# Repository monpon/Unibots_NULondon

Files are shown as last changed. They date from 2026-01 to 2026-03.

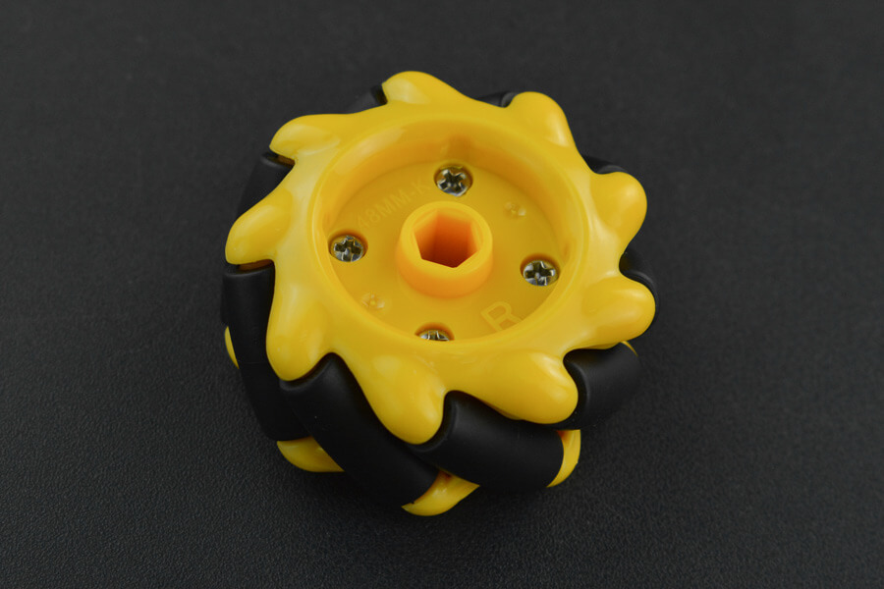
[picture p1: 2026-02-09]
hardware/chassis/FIT0662.jpg

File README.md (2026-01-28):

# Unibots UK Competition Robot

An autonomous robot system designed for the Unibots UK competition, featuring mecanum drive omnidirectional movement, AprilTag-based localization, and autonomous ball collection and launching capabilities.

## Competition Overview

The robot competes in a timed arena-based challenge to:
- Collect magnetic steel ball bearings
- Launch ping-pong balls into scoring nets
- Navigate autonomously with collision avoidance
- Operate within strict size constraints

## System Architecture

### Hardware Components

**Main Controller**
- Raspberry Pi 3 - Primary processing unit

**Motor Control**
- Arduino Uno - Motor control interface with FPID control loops
- 4x Motor encoders - Precise speed feedback for mecanum drive
- ESC units - Electronic speed controllers
- Mecanum wheel drive system - Omnidirectional movement

**Vision System**
- 2x USB webcams:
  - Camera 1: AprilTag localization
  - Camera 2: Ball/gamepiece detection
- AprilTag markers - Localization reference points

**Actuators**
- Ball collection mechanism
- Ping-pong ball launcher

### Software Stack

**Control Architecture**
```
Raspberry Pi 3 (Python)
    ↓ Position Targets via Serial
Arduino Uno (C++)
    ├─ FPID Control Loops (4 motors)
    ├─ Encoder Feedback
    ↓ PWM Signals
ESC Controllers
    ↓ Power
Brushless/DC Motors with Encoders
```

**Key Features**
- Dual camera system: AprilTag localization and object detection
- Encoder-based FPID control for precise mecanum drive
- Distributed control: Pi handles navigation, Arduino handles drive control
- Real-time position targeting with continuous updates
- Autonomous path planning and obstacle avoidance

## Getting Started

### Prerequisites

```bash
# Raspberry Pi dependencies
sudo apt-get update
sudo apt-get install python3-opencv python3-numpy
pip3 install apriltag pyserial

# Arduino IDE for motor control firmware
```

### Installation

```bash
# Clone the repository
git clone <repository-url>
cd unibots-robot/software

# Install Python dependencies
pip3 install -r requirements.txt

# Upload Arduino firmware
# Open arduino/motor_control/motor_control.ino in Arduino IDE
# Select Arduino Uno and upload
```

### Configuration

1. **Camera Calibration**: Calibrate each camera for lens distortion
2. **AprilTag Mapping**: Record arena AprilTag positions
3. **Encoder Calibration**: Calibrate encoder counts per revolution
4. **FPID Tuning**: Tune FPID parameters for each motor
5. **Serial Protocol**: Configure position target communication format

## Project Structure

```
unibots-robot/
├── README.md
├── software/
│   ├── requirements.txt
│   ├── config/
│   │   ├── camera_params.yaml
│   │   ├── apriltag_positions.yaml
│   │   ├── motor_calibration.yaml
│   │   └── fpid_params.yaml
│   ├── src/
│   │   ├── main.py
│   │   ├── vision/
│   │   │   ├── apriltag_detector.py
│   │   │   ├── camera_manager.py
│   │   │   └── localization.py
│   │   ├── navigation/
│   │   │   ├── path_planner.py
│   │   │   ├── obstacle_avoidance.py
│   │   │   └── position_targeting.py
│   │   ├── control/
│   │   │   └── arduino_interface.py
│   │   └── utils/
│   │       └── geometry.py
│   ├── arduino/
│   │   └── motor_control/
│   │       ├── motor_control.ino
│   │       ├── fpid.h
│   │       └── encoder.h
│   ├── tests/
│   │   └── test_localization.py
│   ├── tools/
│   │   ├── calibrate_cameras.py
│   │   ├── calibrate_motors.py
│   │   └── tune_fpid.py
│   └── docs/
│       ├── architecture.md
│       ├── serial_protocol.md
│       ├── calibration_guide.md
│       ├── fpid_tuning.md
│       └── competition_rules.md
└── hardware/
    ├── chassis/
    ├── motor_mounts/
    ├── camera_mounts/
    ├── ball_collector/
    ├── lifter/
    └── assembly/
```

## Usage

### Running the Robot

```bash
# Navigate to software directory
cd software

# Start the main control system
python3 src/main.py

# Run with debug visualization
python3 src/main.py --debug

# Test individual components
python3 tests/test_localization.py
```

### Calibration

```bash
# Camera calibration
python3 tools/calibrate_cameras.py

# Motor calibration
python3 tools/calibrate_motors.py

# FPID tuning
python3 tools/tune_fpid.py
```

## Development

### Key Design Decisions

- **Mecanum Drive**: Chosen for omnidirectional movement and precise positioning
- **Encoder-Based Control**: Four motor encoders provide precise speed feedback for synchronized mecanum drive
- **FPID Control**: Arduino handles real-time FPID loops for each motor, ensuring accurate speed matching
- **Distributed Architecture**: Raspberry Pi 3 handles high-level navigation and sends position targets; Arduino Uno executes low-level drive control
- **Camera-Based Odometry**: AprilTag localization with dedicated camera for position tracking

### Known Issues

- Motor selection: Need motors with integrated or attachable encoders
- Arduino Uno memory constraints with FPID for 4 motors + encoder processing
- Serial communication latency for position target updates
- Camera processing optimization needed for real-time performance with dual cameras

## Competition Constraints

- Initial size limitations must be met
- Full autonomy required (no remote control)
- Collision avoidance mandatory
- AprilTags positioned around arena walls for localization

## Contributing

1. Fork the repository
2. Create a feature branch (`git checkout -b feature/improvement`)
3. Commit changes (`git commit -am 'Add new feature'`)
4. Push to branch (`git push origin feature/improvement`)
5. Open a Pull Request

## Contact

Monesh - moneshpon@gmail.com

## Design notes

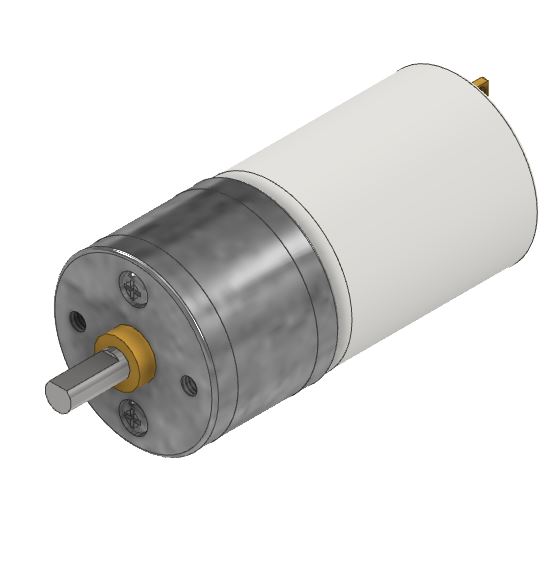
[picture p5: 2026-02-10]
hardware/motor_mounts/25ga-370-280-rpm-dc-motor-1.snapshot.1/25ga-370-280-rpm-dc Motor.JPG

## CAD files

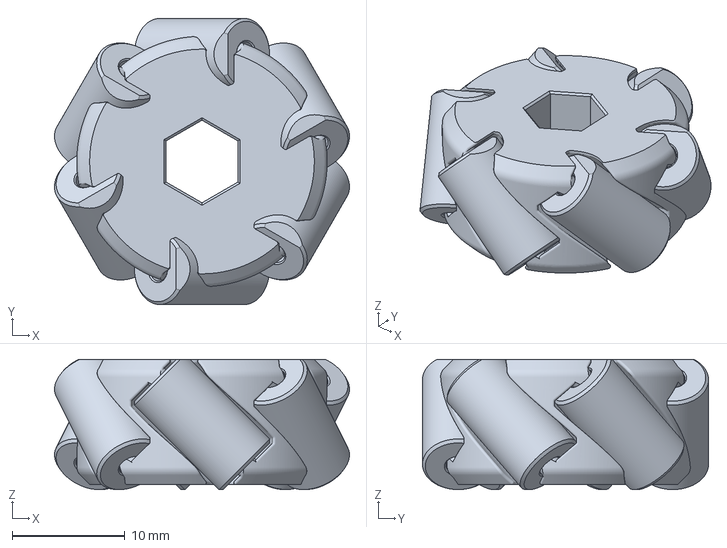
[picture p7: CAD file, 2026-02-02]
hardware/chassis/2910, 2in, Preassembled, 3DP, Mechanum Wheel, Left.3mf
26.2 x 25.4 x 11.6 mm

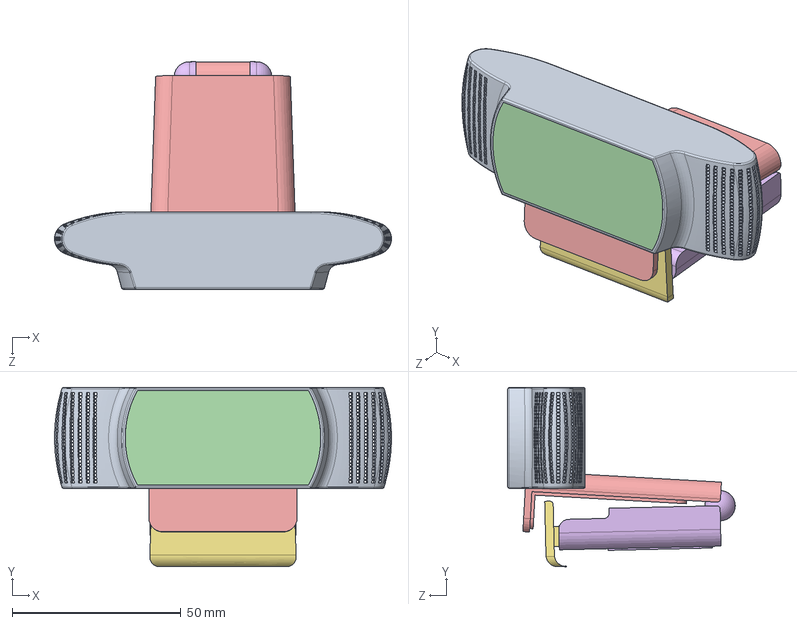
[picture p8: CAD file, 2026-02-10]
hardware/camera_mounts/Camera/Сборка1.SLDASM
100.0 x 53.2 x 67.5 mm
Дет1
Дет2
Дет3
Дет4
Дет5
Дет6
Дет7

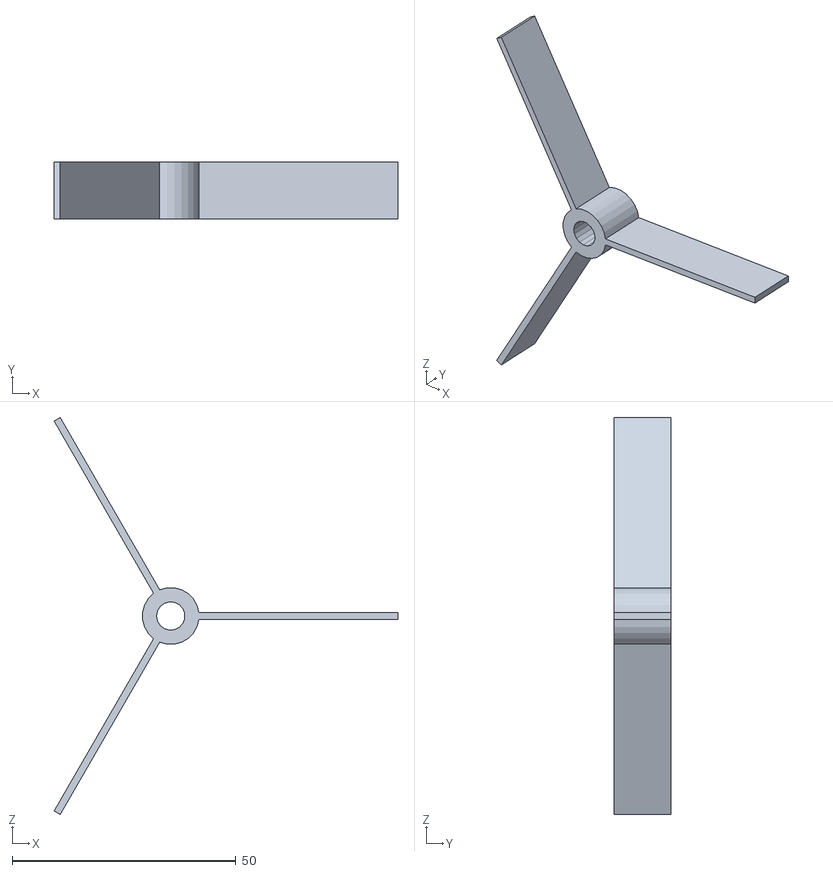
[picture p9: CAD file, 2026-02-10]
hardware/brush/brush_tpu_test_print.stl
76.9 x 12.7 x 88.8

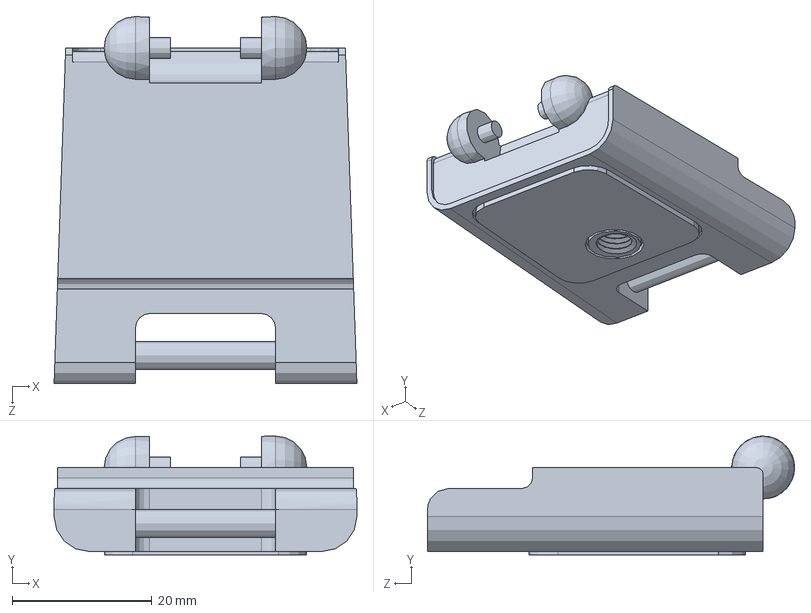
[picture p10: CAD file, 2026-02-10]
hardware/camera_mounts/Camera/Дет6.SLDPRT
43.3 x 17.0 x 52.5 mm

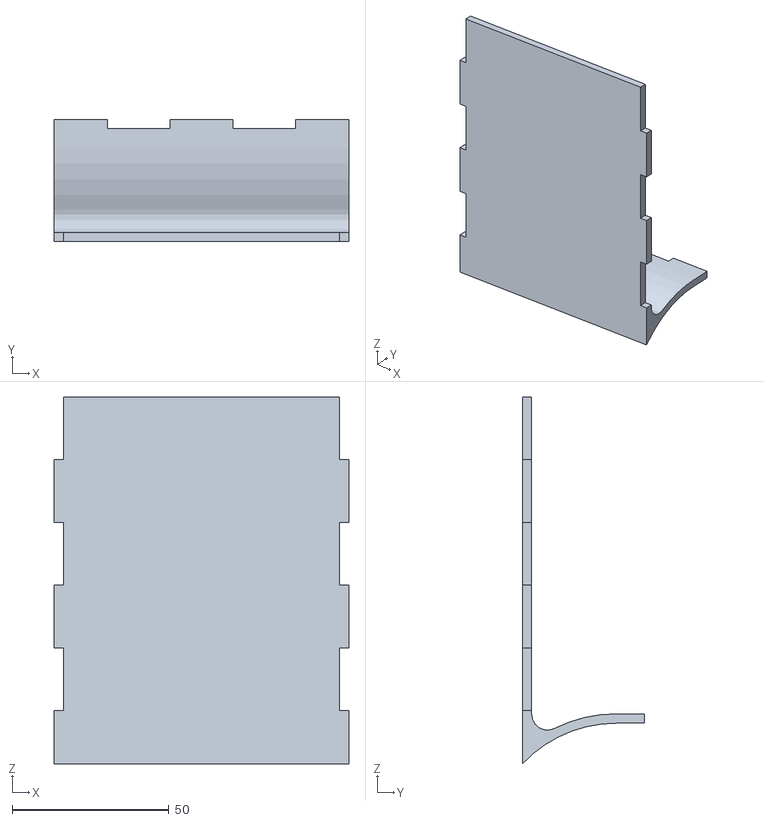
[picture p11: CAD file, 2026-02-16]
hardware/chassis/final/bridge plate.stl
94.0 x 39.0 x 117.0

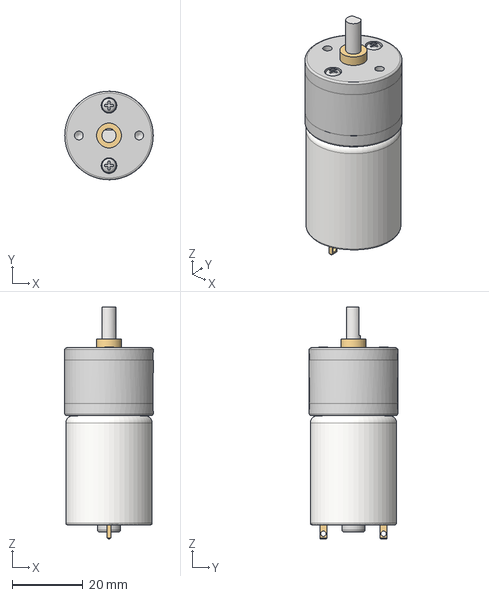
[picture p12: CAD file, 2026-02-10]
hardware/motor_mounts/25ga-370-280-rpm-dc-motor-1.snapshot.1/25ga-370-280-rpm-dc Motor.stp
25.0 x 25.0 x 65.5 mm

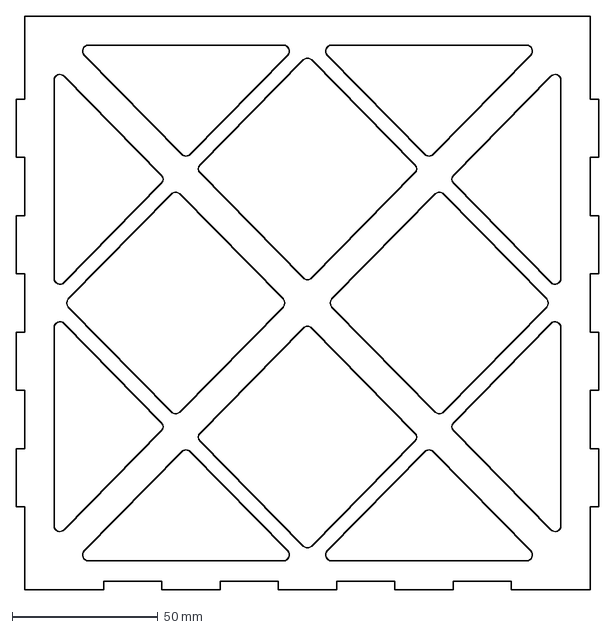
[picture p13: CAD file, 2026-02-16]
hardware/motor_mounts/bottom plate left/Left_Plate.dxf
200.0 x 197.0 mm

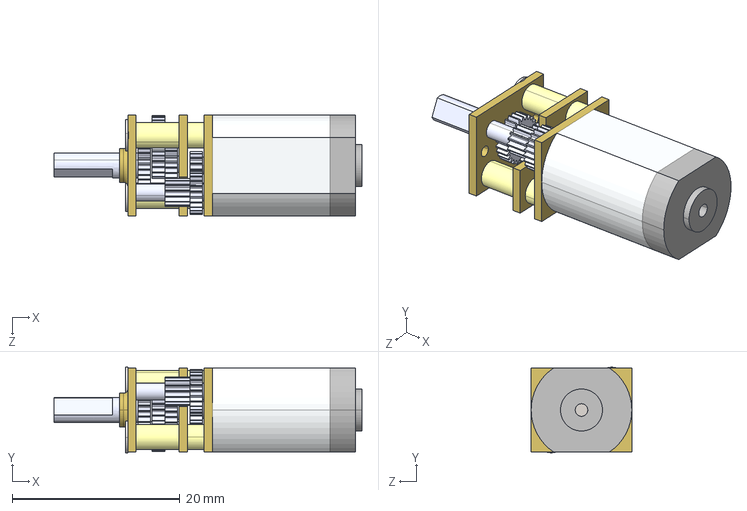
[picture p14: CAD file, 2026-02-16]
hardware/motor_mounts/ga12-n20-motor-1.snapshot.3/GA12-N20 Motor.IGS
36.7 x 10.2 x 12.0 mm

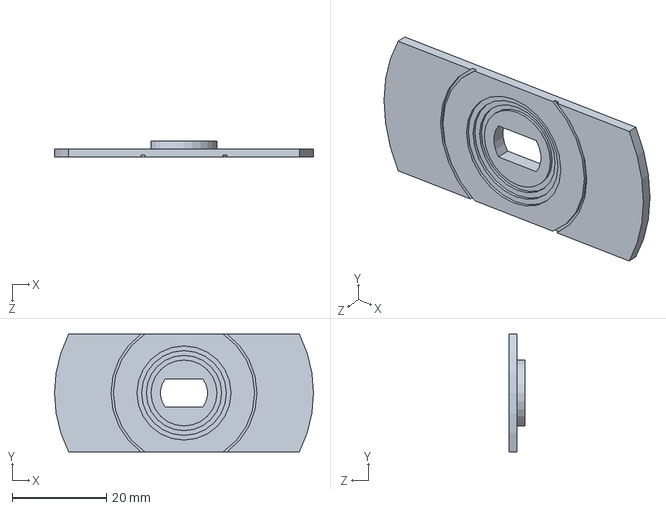
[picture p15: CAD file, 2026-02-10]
hardware/camera_mounts/Camera/Дет3.SLDPRT
55.0 x 25.0 x 3.50 mm

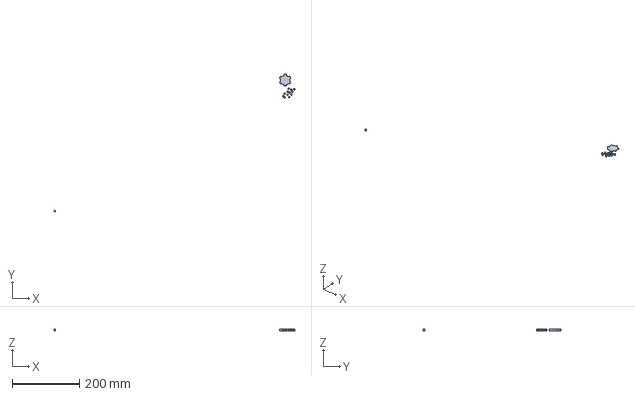
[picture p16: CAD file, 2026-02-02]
hardware/chassis/hub.3mf
718.9 x 411.0 x 5.00 mm
hub.stl
roller.stl x 13

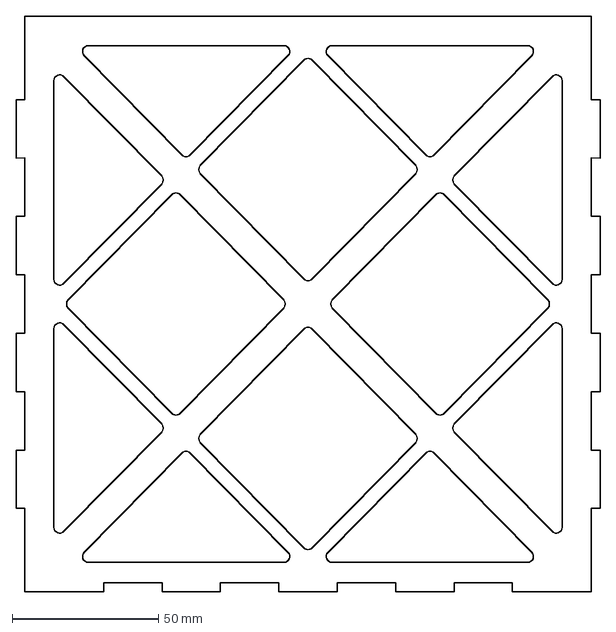
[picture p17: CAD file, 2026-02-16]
hardware/motor_mounts/bottom plate left/Right_Plate.dxf
200.0 x 197.0 mm

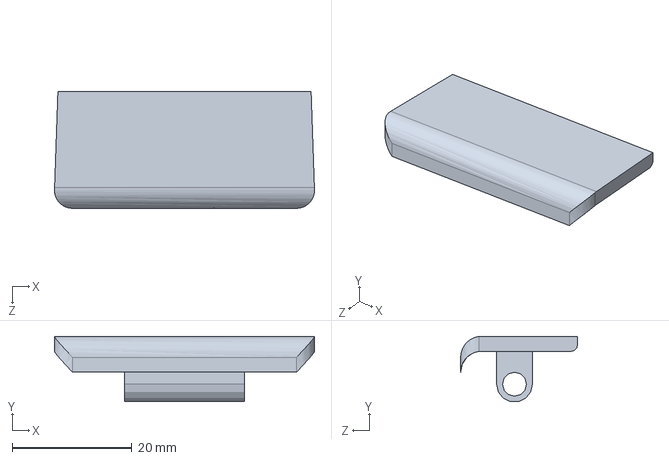
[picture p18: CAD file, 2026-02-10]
hardware/camera_mounts/Camera/Дет7.SLDPRT
43.4 x 10.9 x 19.5 mm

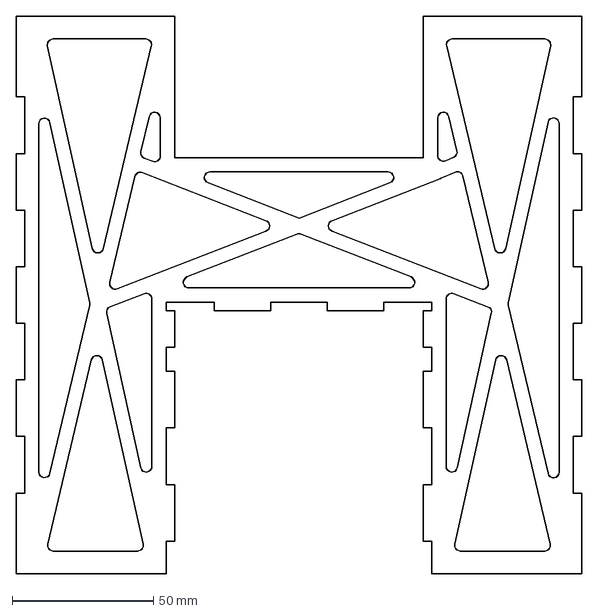
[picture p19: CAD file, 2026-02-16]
hardware/motor_mounts/bottom plate left/Front_Plate.dxf
200.0 x 197.0 mm

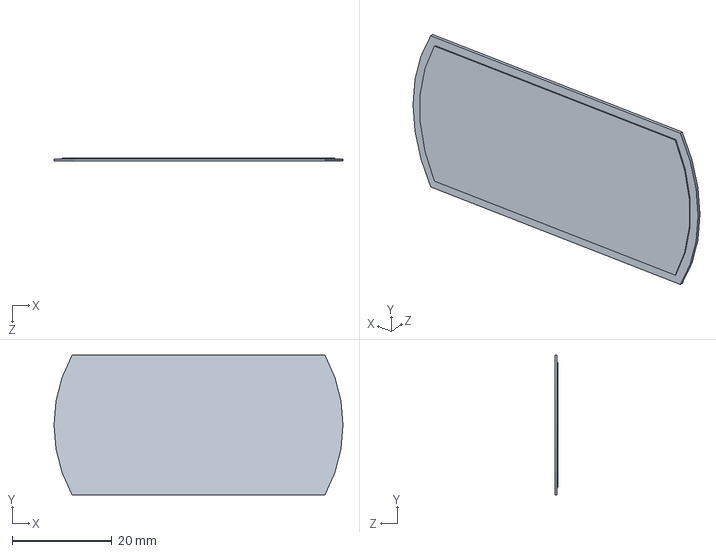
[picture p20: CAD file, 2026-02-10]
hardware/camera_mounts/Camera/Дет4.SLDPRT
58.0 x 28.0 x 0.7 mm

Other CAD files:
hardware/motor_mounts/bottom plate left/Back_Plate.dxf
hardware/camera_mounts/Camera/Дет1.SLDPRT
hardware/motor_mounts/bottom plate left/bottom plate.stl
hardware/camera_mounts/Camera/Дет2.SLDPRT
hardware/brush/OldVersions/brush_tpu_test_print.0002.ipt
hardware/brush/brush.ipt
hardware/brush/brush_tpu_test_print.ipt
hardware/camera_mounts/Camera/Logitech_C920.ipt
hardware/camera_mounts/Camera/Logitech_C920_-_Arm_bottom_-_Tripod_hole_pocket.ipt
hardware/camera_mounts/Camera/Logitech_C920_-_Arm_bottom_foot_-_Hinge_pocket.ipt
hardware/camera_mounts/Camera/Logitech_C920_-_Arm_bottom_hinge.ipt
hardware/camera_mounts/Camera/Logitech_C920_-_Arm_middle_hinge.ipt
hardware/camera_mounts/Camera/Logitech_C920_-_Arm_top.ipt
hardware/camera_mounts/Camera/Logitech_C920_-_Glass.ipt
hardware/camera_mounts/Camera/Дет2.ipt
hardware/camera_mounts/Camera/Дет3.ipt
hardware/camera_mounts/Camera/Дет4.ipt
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

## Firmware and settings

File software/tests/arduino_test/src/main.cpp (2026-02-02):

#include <Arduino.h>

// Motor A (Left)
const int ENA = 9;
const int IN1 = 8;
const int IN2 = 7;

// Motor B (Right)
const int ENB = 10;
const int IN3 = 6;
const int IN4 = 5;

// Forward declarations
void setMotorA(int speed, bool forward);
void setMotorB(int speed, bool forward);
void driveForward(int speed);
void driveBackward(int speed);
void turnLeft(int speed);
void turnRight(int speed);
void stopMotors();

void setup() {
  // Motor A pins
  pinMode(ENA, OUTPUT);
  pinMode(IN1, OUTPUT);
  pinMode(IN2, OUTPUT);

  pinMode(ENB, OUTPUT);
  pinMode(IN3, OUTPUT);
  pinMode(IN4, OUTPUT);
  
  Serial.begin(9600);
  Serial.println("Motor Control Ready");
  Serial.println("Waiting for commands...");
  
  // Start with motors stopped
}

void setMotorA(int speed, bool forward) {
  if (forward) {
    digitalWrite(IN1, LOW);
    digitalWrite(IN2, HIGH);
  } else {
    digitalWrite(IN1, HIGH);
    digitalWrite(IN2, LOW);
  }
  analogWrite(ENA, abs(speed));
}

void setMotorB(int speed, bool forward) {
  if (forward) {
    digitalWrite(IN3, HIGH);
    digitalWrite(IN4, LOW);
  } else {
    digitalWrite(IN3, LOW);
    digitalWrite(IN4, HIGH);
  }
  analogWrite(ENB, abs(speed));
}

void driveForward(int speed) {
  Serial.println("Moving Forward");
  setMotorA(speed, true);
  setMotorB(speed, true);
}

void driveBackward(int speed) {
  Serial.println("Moving Backward");
  setMotorA(speed, false);
  setMotorB(speed, false);
}

void turnLeft(int speed) {
  Serial.println("Turning Left");
  setMotorA(speed, false);  // Left motor backward
  setMotorB(speed, true);   // Right motor forward
}

void turnRight(int speed) {
  Serial.println("Turning Right");
  setMotorA(speed, true);   // Left motor forward
  setMotorB(speed, false);  // Right motor backward
}

void stopMotors() {
  Serial.println("Motors Stopped");
  analogWrite(ENA, 0);
  analogWrite(ENB, 0);
}

void loop() {
  if (Serial.available() > 0) {
    char command = Serial.read();
    
    // Default speed (adjust as needed, 0-255)
    int speed = 255;  // ~40% speed, increase if motors are too slow
    
    switch(command) {
      case 'F':
      case 'f':
        driveForward(speed);
        break;
        
      case 'B':
      case 'b':
        driveBackward(speed);
        break;
        
      case 'L':
      case 'l':
        turnLeft(speed);
        break;
        
      case 'R':
      case 'r':
        turnRight(speed);
        break;
        
      case 'S':
      case 's':
        stopMotors();
        break;
        
      default:
        // Ignore unknown commands
        break;
    }
  }
}

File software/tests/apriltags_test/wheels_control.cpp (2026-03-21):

#include <Arduino.h>

// ============================================================
//  PIN CONFIGURATION — 4 independent motors
//  Assumes two L298N boards (or equivalent 4-channel driver)
// ============================================================

// Front-Left motor
const int EN_FL = 9;
const int IN1_FL = 8;
const int IN2_FL = 7;

// Front-Right motor
const int EN_FR = 10;
const int IN1_FR = 6;
const int IN2_FR = 5;

// Rear-Left motor
const int EN_RL = 3;
const int IN1_RL = 4;
const int IN2_RL = 2;

// Rear-Right motor
const int EN_RR = 11;
const int IN1_RR = 12;
const int IN2_RR = 13;

// ============================================================
//  STATE  (current power per wheel, -255 to +255)
// ============================================================

int pwrFL = 0;
int pwrFR = 0;
int pwrRL = 0;
int pwrRR = 0;

// ============================================================
//  SERIAL PROTOCOL  (115200 baud, newline-terminated)
//
//  M <FL> <FR> <RL> <RR>\n
//      Set each wheel independently.
//      Values: -255 to 255  (negative = backward)
//      Example: "M 200 200 200 200\n"       → forward
//      Example: "M 200 -200 -200 200\n"     → strafe right
//      Example: "M -150 150 -150 150\n"     → rotate CW
//
//  S\n
//      Hard stop all wheels.
//
//  P\n
//      Query — returns current power of all four wheels.
//
//  Arduino replies:
//      "OK <FL> <FR> <RL> <RR>\n"   after M / S
//      "P <FL> <FR> <RL> <RR>\n"    after P
//      "ERR <reason>\n"             on bad input
// ============================================================

// ============================================================
//  SINGLE-MOTOR HELPER
// ============================================================

void applyMotor(int enPin, int in1Pin, int in2Pin, int power)
{
    power = constrain(power, -255, 255);

    if (power > 0)
    {
        digitalWrite(in1Pin, LOW);
        digitalWrite(in2Pin, HIGH);
        analogWrite(enPin, power);
    }
    else if (power < 0)
    {
        digitalWrite(in1Pin, HIGH);
        digitalWrite(in2Pin, LOW);
        analogWrite(enPin, -power);
    }
    else
    { // 0 → active brake
        digitalWrite(in1Pin, LOW);
        digitalWrite(in2Pin, LOW);
        analogWrite(enPin, 0);
    }
}

// ============================================================
//  APPLY ALL FOUR WHEELS
// ============================================================

void applyAll(int fl, int fr, int rl, int rr)
{
    pwrFL = constrain(fl, -255, 255);
    pwrFR = constrain(fr, -255, 255);
    pwrRL = constrain(rl, -255, 255);
    pwrRR = constrain(rr, -255, 255);

    applyMotor(EN_FL, IN1_FL, IN2_FL, pwrFL);
    applyMotor(EN_FR, IN1_FR, IN2_FR, pwrFR);
    applyMotor(EN_RL, IN1_RL, IN2_RL, pwrRL);
    applyMotor(EN_RR, IN1_RR, IN2_RR, pwrRR);
}

void stopMotors()
{
    applyAll(0, 0, 0, 0);
}

// ============================================================
//  SERIAL RESPONSES
// ============================================================

void sendOK()
{
    Serial.print("OK ");
    Serial.print(pwrFL);
    Serial.print(" ");
    Serial.print(pwrFR);
    Serial.print(" ");
    Serial.print(pwrRL);
    Serial.print(" ");
    Serial.println(pwrRR);
}

void sendPower()
{
    Serial.print("P ");
    Serial.print(pwrFL);
    Serial.print(" ");
    Serial.print(pwrFR);
    Serial.print(" ");
    Serial.print(pwrRL);
    Serial.print(" ");
    Serial.println(pwrRR);
}

// ============================================================
//  COMMAND PARSING
// ============================================================

char buf[48];
uint8_t bufIdx = 0;

void processCommand(const char *cmd)
{
    // ---- STOP ----
    if (cmd[0] == 'S' || cmd[0] == 's')
    {
        stopMotors();
        sendOK();
        return;
    }

    // ---- QUERY ----
    if (cmd[0] == 'P' || cmd[0] == 'p')
    {
        sendPower();
        return;
    }

    // ---- MOTOR SET ----
    if (cmd[0] == 'M' || cmd[0] == 'm')
    {
        int fl = 0, fr = 0, rl = 0, rr = 0;
        int parsed = sscanf(cmd + 1, "%d %d %d %d", &fl, &fr, &rl, &rr);
        if (parsed == 4)
        {
            applyAll(fl, fr, rl, rr);
            sendOK();
        }
        else
        {
            Serial.println("ERR need 4 values: FL FR RL RR");
        }
        return;
    }

    Serial.println("ERR unknown cmd");
}

// ============================================================
//  PIN SETUP HELPER
// ============================================================

void setupMotorPins(int en, int in1, int in2)
{
    pinMode(en, OUTPUT);
    pinMode(in1, OUTPUT);
    pinMode(in2, OUTPUT);
}

// ============================================================
//  SETUP / LOOP
// ============================================================

void setup()
{
    setupMotorPins(EN_FL, IN1_FL, IN2_FL);
    setupMotorPins(EN_FR, IN1_FR, IN2_FR);
    setupMotorPins(EN_RL, IN1_RL, IN2_RL);
    setupMotorPins(EN_RR, IN1_RR, IN2_RR);

    stopMotors();

    Serial.begin(115200);
    Serial.println("READY 4WD");
}

void loop()
{
    while (Serial.available())
    {
        char c = Serial.read();

        if (c == '\n' || c == '\r')
        {
            if (bufIdx > 0)
            {
                buf[bufIdx] = '\0';
                processCommand(buf);
                bufIdx = 0;
            }
        }
        else if (bufIdx < sizeof(buf) - 1)
        {
            buf[bufIdx++] = c;
        }
    }
}

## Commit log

2026-01-27 inventor test
    [Part1.ipt]
2026-01-27 setting up git for use
    [Part1.ipt]
2026-01-27 shared camera housing and mount
    [V2_MountHousing.ipt, back mount.ipt]
2026-01-27 shared camera mount
    [back mount.ipt, back_mount.ipt]
2026-01-28 populated repo, added readme
    [V2_MountHousing.ipt, back_mount.ipt]
2026-01-28 working on apriltag detection and localization, initial commit, distance faulty, will fix soon
    [april_tags.py, logger.py, main.cpp]
2026-02-02 added conceptual geo for chassis
    [2910, 2in, Preassembled, 3DP, Mechanum Wheel, Left.3mf, Chassis Conceptual Geo.0002.ipt, Chassis Conceptual Geo.ipt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]
2026-02-03 addded to conceptual geo
    [Chassis Conceptual Geo.0002.ipt, Chassis Conceptual Geo.0004.ipt, Chassis Conceptual Geo.ipt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]
2026-02-09 added wheels to assembly
    [Chassis Conceptual Geo.0004.ipt, Chassis Conceptual Geo.0005.ipt, Chassis Conceptual Geo.ipt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]
2026-02-09 added wheel file
    [Mecanum Left v5.iam]
2026-02-09 feb 9 updates
    [Chassis Conceptual Geo.0005.ipt, Chassis Conceptual Geo.0006.ipt, Chassis Conceptual Geo.ipt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]
2026-02-09 added brush test print
    [brush_tpu_test_print.ipt]
2026-02-10 fixed brush
    [brush_tpu_test_print.0001.ipt, brush_tpu_test_print.ipt]
2026-02-10 added final folder
    [25ga-370-280-rpm-dc Motor.ipt, 25ga-370-280-rpm-dc Motor.stp, bottom plate.0001.ipt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]
2026-02-10 added bottom plate
    [bottom plate.0001.ipt, bottom plate.0002.ipt, bottom plate.ipt]
2026-02-10 added camera
    [Logitech_C920.ipt, Logitech_C920_-_Arm_bottom_-_Tripod_hole_pocket.ipt, Logitech_C920_-_Arm_bottom_foot_-_Hinge_pocket.ipt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]
2026-02-10 finished side walls as well
    [Chassis Conceptual Geo.0006.ipt, Chassis Conceptual Geo.0007.ipt, Chassis Conceptual Geo.ipt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]
2026-02-11 added front and back wall to final assembly
    [back plate.0002.ipt, back plate.ipt, final assembly.0001.iam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]
2026-02-16 designed everything on chassis, still working on inside walls and lift mechanism
    [25ga-370-280-rpm-dc Motor.0014.ipt, 25ga-370-280-rpm-dc Motor.ipt, Back_Plate.dxf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]
2026-02-16 camera housing face
    [camerahouse.0007.ipt, camerahouse.ipt]
